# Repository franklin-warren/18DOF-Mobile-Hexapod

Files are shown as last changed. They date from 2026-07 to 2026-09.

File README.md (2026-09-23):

**18DOF HEXAPOD ROBOT: It's a spider bot with a suite of sensors. Manual joystick control with plans to implement autonomous walking.**


Currently under construction, this represents progress at the end of Stardance. All code is a work in progress. <br>
Inserted are images/videos of the construction process, including photos of assembly, videos of legs moving, as well as CAD screenshots. <br>
Currently in the main programming stage of the design. <br>
<br>
**Key points:**
	<br>
	Derived and programmed a custom inverse kinematics engine in both leg-centric and bot-centric design <br>
	Derived and implemented a cycloidal step path to reduce power draw and servo strain <br>
	Designed a 3 layer PCB stackup to handle high-amp servo draw and sensitive sensor data simultaneously <br>
	Mass-computed 870 000 point leg reachability clouds in Python to assist in step planning <br>
	Implementing closed loop control with FSR step detection, real-time clearance sensor, and IMU. <br>
	Implementing LIDAR room scanning
	Current architecture is ESP32-Pi Zero W via UART, however, there are eventual plans for ROS2 integration

<br>
**Media:**
<br>
**Walk through/work in progress demo:** <br>
https://drive.google.com/file/d/1R8LIc6dlmES_6KmEAEqcxywUw9GedAyd/view?usp=drive_link
<br>
**Video of two legs walking:**<br>
https://github.com/user-attachments/assets/c0b8d58c-5718-43e7-b491-6766b3c93bf8
<br>
CAD and renders:<br>









<br>
Build and samples from my engineering notebook:
<br>





<br>
I am currently taking a linear algebra course, so I will revisit these transformation after midterms. 
<br>


<br>
Note that with some testing and condensing, I did manage to fit the hexapod onto a slimmer profile, small enough for each frame part to be one piece, printed on a standard build size (25x25cm, ish). 
<br>


<br>
Some changes to the electronics layout have been made, although the core components have stayed the same. 

<br>
<br>
**What works:**
<br>
	Full electromechanical assembly
	One side successfully responds to servo mode commands. 
	Noise has been reduced on IIC lines, they now work. 
	Power system works with no shorts.
	Gait math per leg has been derived, robot-centric has been derived (although refinements are in progress). 
	Cycloidal algorithm works near-flawless, no complaints. It reduces servo power by over 500mA (during startup, as opposed to a linear/instant acceleration curve).
<br>
<br>
**What is still to be done:**
<br>
	The other side PCA has to be swapped (scheduled for prior to October 1st)
	Raspberry Pi <-> ESP link must be validated. 
	Major programming and sensor integration.
	Making the robot walk to a demo-worthy standard

<br>
<br>
**Stretch Goals:**
<br>
	LiDAR, either simple point cloud or full SLAM
	Autonomous walking/navigation.

<br>
<br>
Physical Stuff files (.STEP for assembly, zip folders for boards):
<br>
https://drive.google.com/drive/folders/1-5ccQgtat7KWImv0UO3M1iz52NkRRpyl?usp=drive_link
<br>
**Print settings, assembly tips, etc:**
<br>
	Print out of PETG at 4 wall loops and 30% gyroid infill. If the legs are too heavy, there will be too much torque needed, and the servos will be strained. 
	Assembly can follow the CAD for the most part. Ensure all heat sets are as close to straight as possible. 
	Some heat sets are inserted from the reverse side. They may have to be drilled out. Take a 3/32" drill bit or smaller and run it through the hole to clear any plastic,
	then thread a screw all the way through then out. This cuts a thread before assembly. DO NOT damage the brass with the drill bit. 
	All servos should be centered during assembly. The tibia requires +-110 degrees of freedom, so close to exact centering is important. Adjust trim values in code. 
	The femur-tibia bracket must be installed before installing the main tibia piece, as it must flex to fit in. 
	When soldering, test for shorts often. They will break sensitive components. 
	Be careful with batteries. Be careful with the electricity. This draws an estimated 20A. Do not allow the battery to short.

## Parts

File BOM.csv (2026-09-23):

ITEM | APPROX COST | QUANTITY | ITEM COST
LiDAR | 35 | 1 | 35
Servo- DS32 | 18.99 | 18 | 341.82
TOF | 3 | 3 | 9
ESP-32 S3 | 15 | 1 | 15
PCA9685 | 10 | 2 | 20
3D printr filament | 40 | 1 | 40
Incedentals | 50 | 1 | 50
Raspberry Pi | 20 | 1 | 20
 |  | Total | 530.82

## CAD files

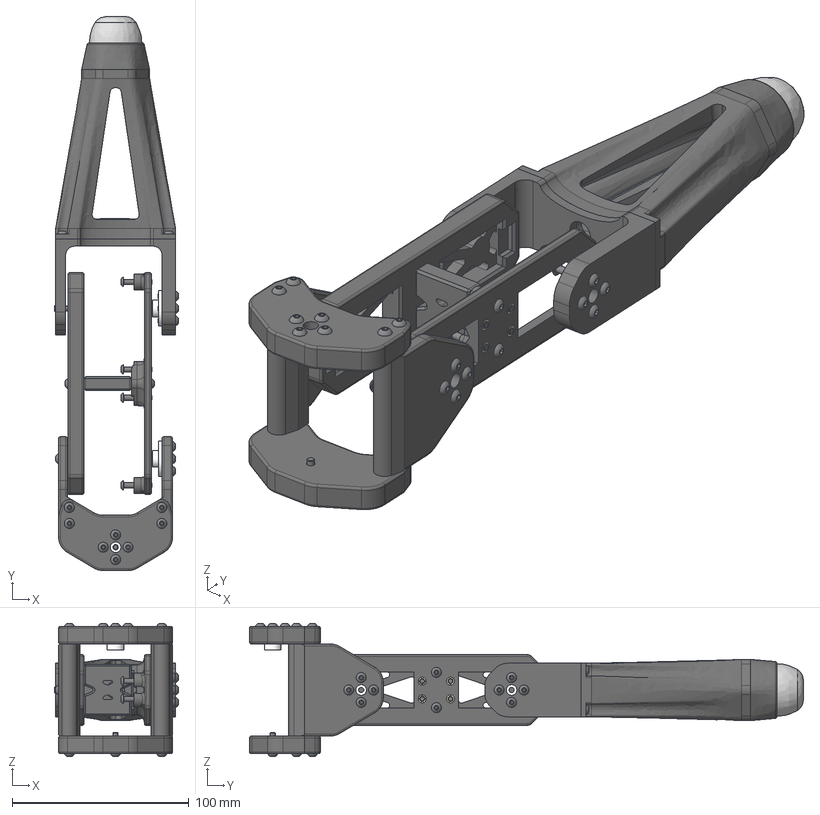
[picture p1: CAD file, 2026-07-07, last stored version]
3D files/Leg Assembly V1.step
70.1 x 313.1 x 75.3 mm
Servo_flush_bracket
Back_bracket
cross brace
M3x4mm (4.5OD 3.9MD) heat set insert x 7
M3x6mm (4.5OD 3.9MD) heat set insert x 20
fake 3x8x4mm bearing x 2
ISO 7380-1 - M3 x 12 Steel 4.6 Black x 5
ISO 7380-1 - M3 x 16 Steel 4.6 Black x 16
Body_Coxa_Servo_Mount_Plate
Bottom_coxa_plate
middle_coxa_piece_LR
servo horn x 3
ISO 7380-1 - M3 x 10 Steel 4.6 Black x 10
test coxa to main body
ISO 7380-1 - M3 x 8 Steel 4.6 Black x 8
bracket
foot
foot mount
connector

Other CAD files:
Leg Assembly V1.step

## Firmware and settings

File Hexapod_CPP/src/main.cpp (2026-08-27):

#include <Arduino.h>
#include <Wire.h>
#include <Adafruit_PWMServoDriver.h>
#include "PCA9685_header.h"

const int esp32_rx = 11;
const int esp32_tx = 12;
const int SDA_main = 8;
const int SCL_main = 9;
const int OE_pin = 18;

//PCA9685 stuff
const int servo_freq = 50;
const int servo_min_us = 500;
const int servo_max_us = 2500;

ChainedServoBoard right_board_270(0x41, servo_freq, servo_min_us, servo_max_us, 270);
ChainedServoBoard left_board_270(0x40, servo_freq, servo_min_us, servo_max_us, 270);

//JOINT MATRIX SETUP
const int LF = 0; //left front
const int LM = 1; //left middle
const int LB = 2; //left back

const int RF = 0; //right front
const int RM = 1; //right middle
const int RB = 2; //right back

const int coxa = 0; 
const int femur = 1;
const int tibia = 2;

const int left_leg_matrix[3][3]= {
    {5, 6, 7}, //LF: coxa on PCA5, femur PCA6, tibia PCA7
    {9, 10, 11}, //same but for LM
    {13, 14, 15} //LB
};

const int right_leg_matrix[3][3]= {
    {10, 9, 8}, //RF: coxa on PCA10, femur PCA9, tibia PCA8
    {6, 5, 4}, //same but for RM
    {2, 1, 0} //RB
};

//SERVO OFFSETS
float left_leg_offsets[3][3]{
    {135.0, 135.0, 135.0+0.0}, //LF coxa, femur, tibia (midpoint 135.0+found offset values)
    {135.0+0.0, 135.0+0.0, 135.0+0.0}, //LM coxa, femur, tibia
    {135+0.0, 135.0+0.0, 135.0+0.0}, //LB coxa, femur, tibia
};

float right_leg_offsets[3][3]{
    {135.0+31.0, 135.0+36.0, 135+33.0}, //RF coxa, femur, tibia (Increasing angle drives coxa forward (CCW), femur up, tibia down)
    {135.0+31.0, 135.0+36.0, 135.0+33.0}, //RM coxa, femur, tibia
    {135.0+31.0, 135.0+36.0, 135.0+0.0}, //RB coxa, femur, tibia
};

//MOVE LEG AND ADD OFFSETS:
void set_left_leg(int leg, int joint, float target_angle){

    int pin = left_leg_matrix[leg][joint]; //looks up which PCA pin is needed
    float offset = left_leg_offsets[leg][joint]; //looks up the offset needed
    float trimmed_angle = target_angle + offset;
    left_board_270.writeAngle(pin, trimmed_angle);

}

void set_right_leg(int leg, int joint, float target_angle){

    int pin = right_leg_matrix[leg][joint]; //looks up which PCA pin is needed
    float offset = right_leg_offsets[leg][joint]; //looks up the offset needed
    float trimmed_angle = target_angle + offset;
    right_board_270.writeAngle(pin, trimmed_angle);
    
}

unsigned long last_watchdog = 0;
const unsigned long watchdog_interval_ms = 500;
bool check_right_next = true;

void servo_watchdog() {
    if (check_right_next) {
        if (right_board_270.isAsleep()) {
            Serial.println("WATCHDOG: 0x41 was asleep, re-waking");
            right_board_270.wake();
        }
    } else {
        if (left_board_270.isAsleep()) {
            Serial.println("WATCHDOG: 0x40 was asleep, re-waking");
            left_board_270.wake();
        }
        
    }
    check_right_next = !check_right_next;
}

void setup() {

  pinMode(OE_pin, OUTPUT);
  digitalWrite(OE_pin, LOW);
  Serial.begin(9600);

  delay(1500);

    Wire.begin(SDA_main, SCL_main);
    Wire.setClock(100000); // Set to 100kHz to stop timeout errors
    right_board_270.begin();
    left_board_270.begin();

  Serial.print("setup done");
    
}
double last_check = millis();


void loop(){

  for (int leg = 0; leg <3; leg++){
    for (int joint = 0; joint <3; joint++){
        set_left_leg(leg, joint, 0.0f);
        set_right_leg(leg, joint, 0.0f);
        delay(5);
    }
       
  }

  if (millis() - last_watchdog >= watchdog_interval_ms) {
    servo_watchdog();
      last_watchdog = millis();
  }

  // // MODE1 check, throttled so it doesn't spam Serial
  // if (millis() - last_check >= 1000) {
  //   Wire.beginTransmission(0x40);
  //   Wire.write(0x00);
  //   Wire.endTransmission();
  //   Wire.requestFrom(0x40, 1);
  //   byte mode1 = Wire.read();
  //   Serial.print("MODE1 (0x40): 0b");
  //   Serial.println(mode1, BIN);

  //   Wire.beginTransmission(0x41);
  //   Wire.write(0x00);
  //   Wire.endTransmission();
  //   Wire.requestFrom(0x41, 1);
  //   byte mode1_b = Wire.read();
  //   Serial.print("MODE1 (0x41): 0b");
  //   Serial.println(mode1_b, BIN);

  //   last_check = millis();
  // }

}

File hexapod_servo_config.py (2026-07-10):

from machine import Pin, I2C
import pca9685
import servo
import time

i2c = I2C(0, sda=Pin(4), scl=Pin(5), freq=400000)

#right legs
right_board_270 = servo.Servos(i2c, address=0x40, freq=200, min_us=500, max_us=2500, degrees=270)

# #left legs
# left_board_270 = servo.Servos(i2c, address=0x41, freq=200, min_us=500, max_us=2500, degrees=270)

#leg setup. R= right, L= left, F= front, M= middle, B=back
RF_coxa = (right_board_270, 6)
RF_femur = (right_board_270, 7)
RF_tibia = (right_board_270, 8)

RM_coxa = (right_board_270, 3)
RM_femur = (right_board_270, 4)
RM_tibia = (right_board_270, 5)

RB_coxa = (right_board_270, 0)
RB_femur = (right_board_270, 1)
RB_tibia = (right_board_270, 2)

# LF_coxa = (left_board_270, 0)
# LF_femur = (left_board_270, 1)
# LF_tibia = (left_board_270, 2)

# LM_coxa = (left_board_270, 3)
# LM_femur = (left_board_270, 4)
# LM_tibia = (left_board_270, 5)

# LB_coxa = (left_board_270, 6)
# LB_femur = (left_board_270, 7)
# LB_tibia = (left_board_270, 8)

def move_servo(joint, degrees):
    board= joint[0] #left or right board
    channel= joint[1] #location of motor (0-15) on PCA
    board.position(channel, degrees=degrees)

right_servos = {
    'RF': {"coxa": (right_board_270, 6), "femur": (right_board_270, 7), "tibia": (right_board_270, 8)}, 
    'RM': {"coxa": (right_board_270, 3), "femur": (right_board_270, 4), "tibia": (right_board_270, 5)}, 
    'RB': {"coxa": (right_board_270, 0), "femur": (right_board_270, 1), "tibia": (right_board_270, 2)}
}

move_servo(RB_coxa, 135)
time.sleep(0.15)
move_servo(RB_femur, 135)
time.sleep(0.15)
move_servo(RB_tibia, 135)
time.sleep(0.15)
move_servo(RB_coxa, 135)
time.sleep(0.15)
move_servo(RB_femur, 135)
time.sleep(0.15)
move_servo(RB_tibia, 135)

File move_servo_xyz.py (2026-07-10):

from formulas.Inverse_Kinematics import get_leg_angles
from hexapod_servo_config import *


def move_servo_xyz(x, y, z):

    angles = get_leg_angles(x, y, z) 

    if angles is not None:
        coxa, femur, tibia = angles

        move_coxa = (coxa)+135
        move_femur = (135 - (femur))
        move_tibia = (135  + (tibia))

        print("Position: ", "(", x,",", y,",", z, ")")

        # print("Coxa angle: ", (coxa))
        move_servo(RB_coxa, move_coxa)
        # print("Coxa moved to: ", move_coxa)

        # print("Femur angle: ", (femur))
        move_servo(RB_femur, move_femur)
        # print("Femur moved to: ", move_femur)

        # print("Tibia angle: ", (tibia))
        move_servo(RB_tibia, move_tibia)
        # print("Tibia moved to: ", move_tibia)
    else:
        print("Position: ", "(", x,",", y,",", z, ")")
        print("Out of Reach")

move_servo(RB_coxa, 135)
move_servo(RM_coxa, 135)
time.sleep(0.15)

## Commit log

2026-07-07 Add files via upload
    First draft (really like 4th but first main draft) of the hexapod's legs
    [Leg Assembly V1.step]
2026-07-07 File management
    [Leg Assembly V1.step]
2026-07-07 tibia joint now 270 degrees
2026-07-08 2 legged step test made
    [Leg Assembly V1.step]
2026-07-09 *UNTESTED*Restructured step pathing
    pretty sure I solved the y-on-an-angle issue found earlier.
    [Non_matrix_step_test.py, hexapod_servo_config.py, move_servo_xyz.py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]
2026-07-10 Made the legs move in a straight line
2026-07-10 Changed RB mounting angle to -45 degrees
2026-08-21 Added ProjectINO files for esp32
2026-09-11 Update README with construction images and videos
    Added images and videos of the construction process, including assembly photos and CAD screenshots.
2026-09-23 Update README with Physical Stuff files link
    Added a link to Physical Stuff files for assembly and boards.
